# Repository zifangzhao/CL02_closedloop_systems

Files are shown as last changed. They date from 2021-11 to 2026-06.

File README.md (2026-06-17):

# CL02 Closed-Loop System

CL02 is a closed-loop electrophysiology trigger controller for detecting configured LFP oscillation features and driving timed stimulation outputs.

The project website is now built from the MkDocs source in [`docs/`](docs/) with configuration in [`mkdocs.yml`](mkdocs.yml). It documents:

- hardware connections and state indicators,
- Windows control-center setup and operation,
- trigger timing and external override behavior,
- firmware update workflow,
- firmware and MATLAB filter-design source locations.

## Local Documentation Preview

```powershell
pip install -r requirements.txt
mkdocs serve
```

For a strict build:

```powershell
mkdocs build --strict --verbose
```

## Repository Areas

| Area | Contents |
| --- | --- |
| `Windows` | CL02 control-center source, installers, and USB driver files. |
| `MCU` | STM32 firmware source, headers, filters, Keil project files, and firmware images. |
| `PCB` | CL02 board files, CAM outputs, assembly files, and BOM assets. |
| `Matlab` | Filter-design and validation scripts. |
| `docs` | MkDocs website source. |

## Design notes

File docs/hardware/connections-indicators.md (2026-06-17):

# Connections and Indicators

The original CL02 hardware note defines four external signal connections and three state indicators.

## Signal Connections

| Label | Role | Range or behavior |
| --- | --- | --- |
| IN0 | Analog input 0 | 0-3.3 V; can be configured with +1.5 V offset. |
| IN1 | Analog input 1 | 0-3.3 V; can be configured with +1.5 V offset. |
| DOUT | Digital trigger output | 0-3.3 V trigger output. |
| AOUT | Analog output | 0-3.3 V analog output. |

## State Indicators

| Indicator | Meaning |
| --- | --- |
| Ready | Closed-loop processor state. Slow blink means waiting; fast blink means estimating baseline; on means ready. |
| Detect | Trigger condition is armed. The final DOUT trigger still depends on stimulator settings. |
| Trigger | DOUT output state. |

!!! warning "Voltage compatibility"
    Check that every connected input accepts CL02 output voltage levels before enabling trigger output. DOUT is documented as 0-3.3 V.

## Bench Check

1. Connect only the bench input signal and a measurement instrument first.
2. Confirm IN0 or IN1 preview in the control center.
3. Confirm Ready state transitions.
4. Confirm DOUT timing and polarity on bench equipment before connecting a stimulator.

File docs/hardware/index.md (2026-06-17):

# Hardware

CL02 hardware exposes two analog inputs, one digital trigger output, one analog output, and visible state indicators for closed-loop state.

<div class="cl02-grid two">
  <a class="cl02-card cl02-card-link" href="connections-indicators/">
    <h3>Connections and indicators</h3>
    <p>IN0, IN1, DOUT, AOUT, and the Ready, Detect, and Trigger state indicators.</p>
  </a>
  <a class="cl02-card cl02-card-link" href="pcb/">
    <h3>PCB and assembly files</h3>
    <p>Public board files, fabrication outputs, and BOM-related files under the repository PCB directory.</p>
  </a>
</div>

<figure class="cl02-image-frame">
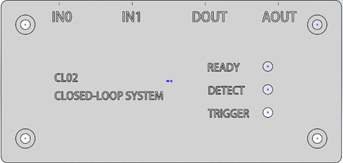
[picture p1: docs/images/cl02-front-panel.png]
CL02 front panel connection labels and state indicators
  
</figure>

## Hardware Asset Map

| Area | Repository path |
| --- | --- |
| V1 board files | [PCB/V1](https://github.com/zifangzhao/CL02_closedloop_systems/tree/V2.2/PCB/V1) |
| V2 board files | [PCB/V2](https://github.com/zifangzhao/CL02_closedloop_systems/tree/V2.2/PCB/V2) |
| V2 CAM outputs | [PCB/V2/CAMOutputs](https://github.com/zifangzhao/CL02_closedloop_systems/tree/V2.2/PCB/V2/CAMOutputs) |
| Firmware images | [MCU/MDK-ARM](https://github.com/zifangzhao/CL02_closedloop_systems/tree/V2.2/MCU/MDK-ARM) |
| Windows control software | [Windows](https://github.com/zifangzhao/CL02_closedloop_systems/tree/V2.2/Windows) |

## Compatibility Record

For each CL02 build or dataset, record:

| Record | Why it matters |
| --- | --- |
| PCB revision | Distinguishes board files and connector details. |
| Firmware filename | Ties trigger and DSP behavior to a specific image. |
| Control-center installer | Defines UI and serial command behavior. |
| Input source | Identifies signal range, offset, and coupling assumptions. |
| Output destination | Defines DOUT or AOUT interpretation by downstream hardware. |

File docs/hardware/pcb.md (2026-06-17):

# PCB and Assembly Files

The repository contains CL02 board assets for multiple revisions.

## Public Board Files

| Revision | Assets |
| --- | --- |
| V1 | `PCB/V1/CL02.sch`, `PCB/V1/CL02.brd`, and `CL02_default_BOM_values.xlsx`. |
| V2 | `PCB/V2/CL02_V2.sch`, `PCB/V2/CL02_V2.brd`, project files, CAM outputs, and assembly files. |

## Fabrication Outputs

The V2 folder includes CAM outputs:

- `PCB/V2/CAMOutputs/GerberFiles`
- `PCB/V2/CAMOutputs/DrillFiles`
- `PCB/V2/CAMOutputs/Assembly`
- `PCB/V2/CAMOutputs/CL02_V2_BOM.xlsx`
- `PCB/V2/CAMOutputs/CL02_V2.zip`

## Documentation Practice

When documenting or reproducing a CL02 build, include the board revision, CAM output archive, BOM file, firmware image, and Windows control-center version. Do not infer connector behavior from board-file names alone; verify against the hardware labels and bench measurements.

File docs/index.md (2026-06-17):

---
hide:
  - navigation
  - toc
---

<section class="cl02-hero">
  <div>
    <h1>A compact closed-loop controller for LFP-triggered stimulation</h1>
    <p>CL02 detects configured local-field-potential oscillation features from analog inputs and drives timed trigger outputs for closed-loop electrophysiology experiments.</p>
    <div class="cl02-actions">
      <a class="md-button md-button--primary" href="getting-started/">Get Started</a>
      <a class="md-button" href="hardware/">Hardware</a>
      <a class="md-button" href="software/">Software</a>
      <a class="md-button" href="firmware-analysis/">Firmware</a>
      <a class="md-button" href="https://github.com/zifangzhao/CL02_closedloop_systems">GitHub</a>
    </div>
    <div class="cl02-signal-row">
      <span>IN0 and IN1 analog inputs</span>
      <span>DOUT trigger output</span>
      <span>AOUT analog output</span>
      <span>1 kHz DSP workflow</span>
      <span>Windows control center</span>
    </div>
  </div>
  <div class="cl02-hero-media cl02-hero-media-tiled">
    <figure class="cl02-hero-tile cl02-device-tile">
      CL02 front panel with IN0, IN1, DOUT, AOUT, and status indicators
      <figcaption class="cl02-caption">The CL02 front panel exposes two analog inputs, digital and analog outputs, and three state indicators for closed-loop readiness and trigger state.</figcaption>
    </figure>
    <figure class="cl02-hero-tile cl02-ui-tile">
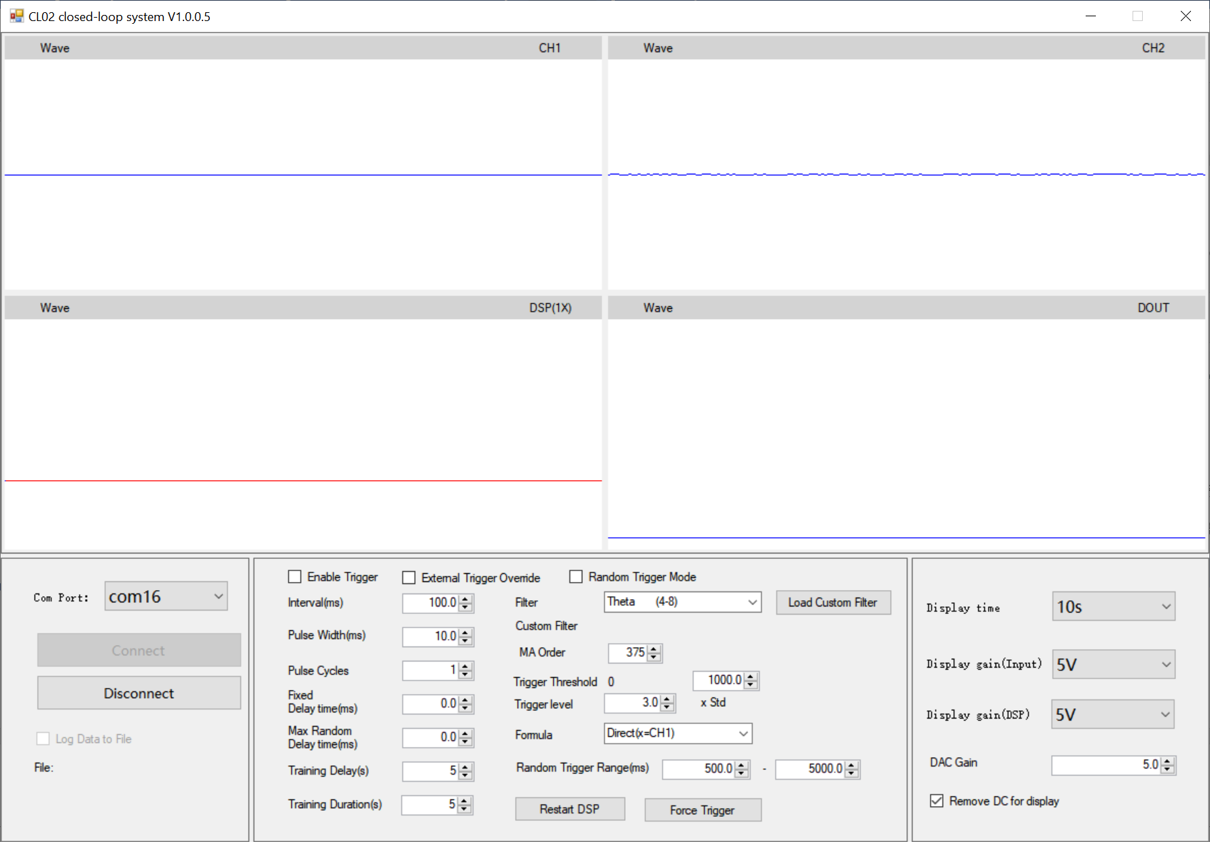
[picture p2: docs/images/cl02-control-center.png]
CL02 Windows control center showing waveforms and trigger settings
      
    </figure>
  </div>
</section>

<section class="cl02-section">
  <div class="cl02-grid two">
    <div class="cl02-card">
      <h2>Current Public Workflow</h2>
      <p><strong>Stable public scope:</strong> connect the CL02 device over USB, configure filters and trigger timing in the Windows control center, and use DOUT or AOUT to drive downstream stimulation hardware.</p>
    </div>
    <div class="cl02-card">
      <h2>Release Record</h2>
      <p>Record the installer file, firmware image, PCB revision, filter file, stimulus timing parameters, and threshold settings with each experiment so trigger behavior remains reproducible.</p>
    </div>
  </div>

  <div class="cl02-grid">
    <div class="cl02-card">
      <h3>Run a first bench test</h3>
      <p><a href="getting-started/installation/">Install</a> -> <a href="getting-started/first-run/">connect</a> -> configure a conservative trigger -> verify DOUT timing.</p>
    </div>
    <div class="cl02-card">
      <h3>Prepare hardware</h3>
      <p><a href="hardware/connections-indicators/">Connection map</a> -> status indicators -> stimulator input checks -> PCB revision notes.</p>
    </div>
    <div class="cl02-card">
      <h3>Tune detection</h3>
      <p><a href="software/filters/">Filter choice</a> -> moving-average order -> baseline training window -> threshold or trigger-level setting.</p>
    </div>
    <div class="cl02-card">
      <h3>Update firmware</h3>
      <p><a href="getting-started/firmware-update/">DFU mode</a> -> choose a repository firmware image -> upgrade -> return the switch to Run mode.</p>
    </div>
  </div>
</section>

<section class="cl02-section">
  <h2>Closed-Loop Signal Path</h2>
  <p>CL02 routes analog input through configured filtering and trigger control before asserting the stimulation output.</p>
  <div class="cl02-flow" aria-label="CL02 signal path">
    <div>Analog input</div>
    <div>DSP filter</div>
    <div>Envelope or metric</div>
    <div>Baseline training</div>
    <div>Threshold test</div>
    <div>DOUT or AOUT</div>
  </div>
</section>

<section class="cl02-section">
  <h2>Interface and I/O Summary</h2>
  <div class="cl02-spec-scroll" role="region" aria-label="CL02 input output summary" tabindex="0">
    <table class="cl02-spec-table">
      <thead>
        <tr>
          <th>Signal or control</th>
          <th>Public behavior</th>
          <th>Documentation entry</th>
        </tr>
      </thead>
      <tbody>
        <tr><td>IN0</td><td>Analog input 0, 0-3.3 V, configurable with +1.5 V offset.</td><td><a href="hardware/connections-indicators/">Connections</a></td></tr>
        <tr><td>IN1</td><td>Analog input 1, 0-3.3 V, configurable with +1.5 V offset.</td><td><a href="hardware/connections-indicators/">Connections</a></td></tr>
        <tr><td>DOUT</td><td>Digital trigger output, 0-3.3 V.</td><td><a href="software/trigger-logic/">Trigger Logic</a></td></tr>
        <tr><td>AOUT</td><td>Analog output, 0-3.3 V.</td><td><a href="hardware/connections-indicators/">Connections</a></td></tr>
        <tr><td>Ready</td><td>Closed-loop processor state: slow blink while waiting, fast blink while estimating baseline, on when ready.</td><td><a href="hardware/connections-indicators/">Indicators</a></td></tr>
        <tr><td>Detect</td><td>Indicates that a trigger condition is armed; DOUT behavior still depends on stimulator settings.</td><td><a href="hardware/connections-indicators/">Indicators</a></td></tr>
        <tr><td>Trigger</td><td>Indicates DOUT state.</td><td><a href="hardware/connections-indicators/">Indicators</a></td></tr>
      </tbody>
    </table>
  </div>
</section>

<section class="cl02-section">
  <h2>Operator Controls</h2>
  <p>The Windows control center presents waveform preview, serial connection, trigger timing, DSP filter selection, and display scaling in one bench-facing interface.</p>
  <div class="cl02-grid">
    <div class="cl02-card">
      <h3>Connection</h3>
      <p>Choose the COM port, connect to the device, and optionally log data to a file during preview.</p>
    </div>
    <div class="cl02-card">
      <h3>Trigger timing</h3>
      <p>Set interval, pulse width, pulse cycles, fixed delay, random delay, and training delay or duration.</p>
    </div>
    <div class="cl02-card">
      <h3>DSP configuration</h3>
      <p>Select filter, formula, moving-average order, trigger threshold, trigger level, and optional custom filters.</p>
    </div>
    <div class="cl02-card">
      <h3>Manual checks</h3>
      <p>Restart DSP or force a trigger during bench validation before moving to experiment hardware.</p>
    </div>
    <div class="cl02-card">
      <h3>External override</h3>
      <p>Read an int32 control value from <code>d:\cl02_control.bin</code> to mask DOUT in the experimental override workflow.</p>
    </div>
    <div class="cl02-card">
      <h3>Display scaling</h3>
      <p>Select display time, input gain, DSP gain, DAC gain, and optional DC removal for waveform review.</p>
    </div>
  </div>
</section>

<section class="cl02-section">
  <h2>System Overview</h2>
  <p>A typical session starts with a bench connection, then moves through filter selection, baseline training, trigger verification, and experiment logging.</p>
  <figure class="cl02-image-frame">
    CL02 Windows control center with waveform and closed-loop settings
  </figure>
</section>

<section class="cl02-section">
  <h2>Quick Start</h2>
  <div class="cl02-grid two">
    <div class="cl02-card">
      <h3>Install software</h3>
      <p>Use the installer under <code>Windows</code> and install the CL02 USB driver manually if Windows does not bind a usable COM port.</p>
    </div>
    <div class="cl02-card">
      <h3>Connect hardware</h3>
      <p>Wire IN0 or IN1, connect DOUT or AOUT to the downstream device, and confirm voltage compatibility before enabling triggers.</p>
    </div>
    <div class="cl02-card">
      <h3>Train and trigger</h3>
      <p>Select filter, moving-average order, training window, threshold, interval, pulse width, and delay before enabling output.</p>
    </div>
    <div class="cl02-card">
      <h3>Save a record</h3>
      <p>Log the installer version, firmware file, trigger settings, filter file, and hardware connections used for the run.</p>
    </div>
  </div>
</section>

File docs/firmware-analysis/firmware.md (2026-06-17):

# Firmware

CL02 firmware source is organized under `MCU`.

## High-Signal Source Files

| File | Role |
| --- | --- |
| `MCU/Src/CE32_ClosedLoop.c` | Closed-loop modes, baseline training, threshold checks, random-trigger update, and trigger actions. |
| `MCU/Src/CE32_StimControl.c` | Stimulation-control behavior and output timing support. |
| `MCU/Src/CE32_COMMAND.c` | Command handling for host-device communication. |
| `MCU/Src/CL02_Server.c` | CL02 server-side firmware behavior. |
| `MCU/Inc/CE32_filterDef.h` | Filter coefficient include map. |
| `MCU/Inc/CE32_ClosedLoop.h` | Closed-loop type and interface definitions. |

## Firmware Images

Prebuilt images and historical images are under `MCU/MDK-ARM`. Record the exact image filename used in each run.

## Firmware Behavior Notes

The firmware source includes closed-loop modes such as disabled, single, double, cascade, gated, random, and Hilbert-transform variants. Public experiment notes should state the mode and filter path used rather than relying only on a UI screenshot.

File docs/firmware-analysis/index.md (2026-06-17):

# Firmware and Analysis

The CL02 repository includes STM32 firmware source, firmware image artifacts, and MATLAB tools for filter design and validation.

<div class="cl02-grid two">
  <a class="cl02-card cl02-card-link" href="firmware/">
    <h3>Firmware</h3>
    <p>STM32 source files, command handling, closed-loop logic, stimulation control, and prebuilt images.</p>
  </a>
  <a class="cl02-card cl02-card-link" href="matlab/">
    <h3>MATLAB tools</h3>
    <p>Filter design, coefficient generation, validation scripts, and file-control example workflows.</p>
  </a>
</div>

## Core Repository Areas

| Area | Purpose |
| --- | --- |
| `MCU/Src` | Firmware source files, including command, closed-loop, stimulation, data, USB, and UART modules. |
| `MCU/Inc` | Firmware headers and generated filter coefficient headers. |
| `MCU/MDK-ARM` | Keil project files and firmware image artifacts. |
| `Matlab` | Filter-design and validation scripts. |
| `Windows` | Control-center application and installer assets. |

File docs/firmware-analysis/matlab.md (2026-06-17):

# MATLAB Tools

The `Matlab` folder contains scripts for filter generation, validation, and helper workflows.

## Key Files

| File | Role |
| --- | --- |
| `CL02_filterDesigner.m` | CL02 filter design entry point. |
| `CL02_genFilter_withData.m` | Filter generation using data-driven workflow. |
| `script_validate_CL02_filterDesigner.m` | Minimal validation entry for CL02 filter design. |
| `CE32_filterDesigner.m` | Shared CE32 filter design helper. |
| `CE32_filterGen_SOS.m` | Second-order-section coefficient generation. |
| `CE32_filterDef.h` | Generated or source filter definition map used by firmware-side includes. |
| `readmulti_frank.m` | MATLAB data helper included in the repository. |

## Validation Example

The repository validation script constructs a filter and opens MATLAB visualization:

```matlab
Hd=CE32_filterDesigner(100,1000,2);
fvtool(Hd,'fs',1000);
```

## Documentation Practice

When custom filters are used, preserve:

1. The MATLAB script version.
2. The input parameters.
3. The generated coefficient file.
4. The firmware image that consumed the coefficients.
5. The control-center screenshot or parameter export for the run.

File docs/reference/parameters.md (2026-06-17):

# Parameters

This table mirrors the public control-center parameters described in the original README and visible UI.

| Parameter | Meaning |
| --- | --- |
| Connect | Start communication with the connected CL02 device. |
| Disconnect | Disconnect the device; the original note states the device remains in its state. |
| Enable Trigger | Enable DOUT signaling. |
| External Trigger Override | Experimental file-based int32 override used to mask DOUT. |
| Interval | Minimum trigger interval, in milliseconds. |
| Pulse width | Width of each individual trigger pulse, in milliseconds. |
| Pulse cycles | Number of pulse cycles in a trigger event. |
| Fixed delay | Fixed delay between trigger detection and DOUT output. |
| Max random delay | Random delay range added between trigger detection and DOUT output. |
| Train start | Delay before closed-loop processor initiation after setting. |
| Train duration | Baseline calculation window duration. |
| MA order | Moving-average window order in samples; the original note references `fs=1000`. |
| Filter | DSP filter selection. |
| Custom filter | Operator-loaded filter file. |
| Trigger threshold | Absolute threshold setting. |
| Trigger level | Trigger threshold based on a multiple of baseline level. |
| Formula | Input signal selected for DSP computation. |
| Random trigger range | Time range between triggers in random-trigger mode. |
| Display time | Waveform preview time window. |
| Display gain | Waveform scaling for input and DSP preview. |
| DAC gain | Analog-output gain setting. |
| Remove DC for display | Display-side DC removal for waveform preview. |

## Experiment Record Minimum

At minimum, save the firmware image, installer version, PCB revision, input channel, output channel, filter, trigger threshold or trigger level, train start, train duration, interval, pulse width, delay settings, and whether external override was enabled.

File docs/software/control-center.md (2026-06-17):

# Control Center

The CL02 control center is the main operator interface for connecting the device, viewing waveforms, and configuring closed-loop behavior.

<figure class="cl02-image-frame">
  CL02 Windows control center
</figure>

## Main Areas

| Area | Purpose |
| --- | --- |
| Waveform panels | Preview CH1, CH2, DSP output, and DOUT state. |
| COM port and connect buttons | Select the serial port, connect, disconnect, and optionally log data to file. |
| Trigger timing controls | Set interval, pulse width, pulse cycles, fixed delay, random delay, training delay, and training duration. |
| DSP controls | Select filter, custom filter, moving-average order, threshold, trigger level, and formula. |
| Manual actions | Restart DSP or force trigger for controlled bench validation. |
| Display controls | Select display time, input gain, DSP gain, DAC gain, and DC removal. |

## Connection Flow

1. Select the COM port.
2. Connect.
3. Review waveform preview.
4. Configure output timing and DSP settings.
5. Enable trigger only after bench validation.
6. Disconnect before rewiring hardware.

!!! tip "Record parameter values"
    A screenshot is useful, but the experiment note should include the actual trigger interval, pulse width, delay, filter, moving-average order, threshold, and firmware image.

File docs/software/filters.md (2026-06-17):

# Filters

CL02 includes built-in filter coefficient headers and MATLAB tools for generating filter definitions.

## Built-In Filter Families

The firmware include tree contains filter headers for commonly used bands, including delta, theta, alpha, beta, gamma, high-gamma, epilepsy-band, sharp-wave, ripple, and ripple-1 style entries. The public headers include band-pass filters, low-pass filters, and Hilbert-transform filter variants at the CL02 DSP sample-rate workflow.

Examples from `MCU/Inc/CE32_filterDef.h` include:

| Family | Representative headers |
| --- | --- |
| Delta | `fdacoefs_BPF_D_1.5_5.5Hz@1000_ord1_SOS.h` |
| Theta | `fdacoefs_BPF_T_4_12Hz@1000_ord1_SOS.h` |
| Alpha | `fdacoefs_BPF_A_8_13Hz@1000_ord1_SOS.h` |
| Beta | `fdacoefs_BPF_B_13_30Hz@1000_ord1_SOS.h` |
| Gamma | `fdacoefs_BPF_G_30_80Hz@1000_ord1_SOS.h` |
| Ripple | `fdacoefs_BPF_R_110_250Hz@1000_ord1_SOS.h` |
| Ripple 1 | `fdacoefs_BPF_R1_100_200Hz@1000_ord1_SOS.h` |

## Custom Filters

The control center exposes custom filter loading. Keep custom filter files alongside the experiment record and document which DSP channel used each file.

## MATLAB Filter Tools

The `Matlab` folder contains CL02 and CE32 filter-design scripts, including `CL02_filterDesigner.m`, `CE32_filterDesigner.m`, and validation scripts. Use these scripts as the auditable source for generated coefficients rather than hand-editing coefficient headers.

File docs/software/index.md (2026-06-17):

# Software

CL02 software centers on the Windows control application for waveform preview, DSP and trigger configuration, serial communication, and output testing.

<div class="cl02-grid two">
  <a class="cl02-card cl02-card-link" href="control-center/">
    <h3>Control Center</h3>
    <p>Waveform panels, COM-port connection, trigger timing, filter selection, custom filter loading, and display scaling.</p>
  </a>
  <a class="cl02-card cl02-card-link" href="trigger-logic/">
    <h3>Trigger Logic</h3>
    <p>Training window, baseline estimation, threshold or level logic, pulse width, interval, delay, and random-delay behavior.</p>
  </a>
  <a class="cl02-card cl02-card-link" href="external-control/">
    <h3>External Control</h3>
    <p>Experimental int32 file override through <code>d:\cl02_control.bin</code>.</p>
  </a>
  <a class="cl02-card cl02-card-link" href="filters/">
    <h3>Filters</h3>
    <p>Built-in oscillation bands, moving-average order, custom filter files, and MATLAB filter-generation tools.</p>
  </a>
</div>

<figure class="cl02-image-frame">
  CL02 control center overview
</figure>

## Control Surface

The control center combines four display panels with trigger and DSP configuration. Public documentation should treat screenshots as operator guidance, not a replacement for recording the exact parameter values used in a run.

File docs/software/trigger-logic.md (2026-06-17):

# Trigger Logic

CL02 trigger behavior combines DSP output, baseline training, threshold logic, timing constraints, and output gating.

<figure class="cl02-image-frame">
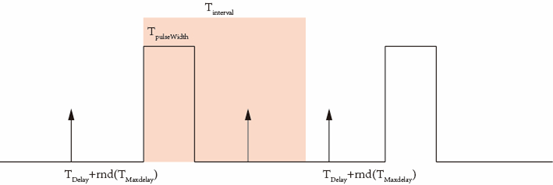
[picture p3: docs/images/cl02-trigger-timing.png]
CL02 trigger timing diagram showing delay, random delay, pulse width, and interval
  
</figure>

## Timing Controls

| Parameter | Meaning |
| --- | --- |
| Interval | Minimum interval between triggers, in milliseconds. |
| Pulse width | Width of each individual trigger pulse, in milliseconds. |
| Pulse cycles | Number of pulse cycles in the configured output event. |
| Fixed delay | Fixed delay added between trigger detection and DOUT assertion. |
| Max random delay | Maximum random delay added between detection and DOUT assertion. |
| Train start | Delay before closed-loop processor training begins. |
| Train duration | Baseline calculation window duration. |

## Detection Controls

| Parameter | Meaning |
| --- | --- |
| MA order | Moving-average window order. The original README notes sample units with `fs=1000`. |
| Filter | Built-in or custom filter used by the DSP path. |
| Trigger threshold | Absolute trigger threshold setting. |
| Trigger level | Threshold based on a multiple of the baseline level. |
| Formula | Input signal selected for DSP computation. |
| Random trigger range | Time range between triggers in random-trigger mode. |

## Recommended Validation

1. Disable trigger output while confirming signal preview.
2. Confirm the baseline state reaches Ready.
3. Enable output with conservative interval and pulse width.
4. Measure DOUT timing externally.
5. Document configured timing and measured timing.

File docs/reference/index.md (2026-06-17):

# Reference

The reference section collects operator parameters, troubleshooting notes, and contribution guidance.

<div class="cl02-grid two">
  <a class="cl02-card cl02-card-link" href="parameters/">
    <h3>Parameters</h3>
    <p>Control-center parameter names and the public behavior documented in the original instructions.</p>
  </a>
  <a class="cl02-card cl02-card-link" href="troubleshooting/">
    <h3>Troubleshooting</h3>
    <p>Connection, driver, DFU, trigger, and external-control checks.</p>
  </a>
  <a class="cl02-card cl02-card-link" href="contributing/">
    <h3>Contributing</h3>
    <p>How to keep CL02 documentation source-faithful and reproducible.</p>
  </a>
</div>

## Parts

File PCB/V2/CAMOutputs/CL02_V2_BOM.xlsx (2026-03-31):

Qty | Value | Device | Package | Parts | Description | BOM | MF | MPN | OC_FARNELL | OC_NEWARK | POPULARITY | SPICEMODEL | SPICEPREFIX
5 |  | LED0603 | CHIPLED_0603 | DET, ENABLE, PWR, READY, STIM | https://www.digikey.com/en/products/detail/liteon/LTST-C194TBKT/2356225
1 | 0Ohm | SOLDERJUMPER | SOLDERJUMPER_ARROW_NOPASTE | SJ1 | https://www.digikey.com/en/products/detail/yageo/RC0402JR-070RL/726406
1 |  | SWITCH_DPDT | DPDT_SMT_JS202011SCQN | SW1 | https://www.digikey.com/en/products/detail/c-k/JS202011SCQN/2094299?s=N4IgTCBcDaIFIGUwAYUEY0IMIEUByIAugL5A
3 | 1.5k | RR0402 | R0402 | R5, R6, R7 | https://www.digikey.com/en/products/detail/panasonic-electronic-components/ERA-2AEB152X/1706009 |  |  |  |  |  |  | NONE | R
3 | 100k | RR0402 | R0402 | R9, R11, R13 | https://www.digikey.com/en/products/detail/yageo/RC0402FR-07100KL/726526 |  |  |  |  |  |  | NONE | R
13 | 10k | RR0402 | R0402 | R1, R2, R3, R4, R8, R10, R12, R14, R15, R16, R23, R24, R25 | https://www.digikey.com/en/products/detail/yageo/RC0402JR-0710KL/726418 |  |  |  |  |  |  | NONE | R
15 | 10u | CC0402 | C0402 | C3, C4, C5, C6, C7, C8, C9, C10, C11, C14, C15, C16, C18, C19, C22 | https://www.digikey.com/en/products/detail/samsung-electro-mechanics/CL05A106MP5NUNC/3887108 |  |  |  |  |  |  | NONE | C
2 | 18p | CC0402 | C0402 | C1, C2 | https://www.digikey.com/en/products/detail/kemet/CBR04C180F5GAC/3479640 |  |  |  |  |  |  | NONE | C
1 | 2.54MM_2X5 | 2.54MM_2X5 | 2.54MM_2X5 | U$9 | https://www.digikey.com/en/products/detail/sullins-connector-solutions/SFH11-PBPC-D05-ST-BK/1990087
1 | 20k | RR0402 | R0402 | R17 | https://www.digikey.com/en/products/detail/yageo/RC0402FR-0720KL/726557 |  |  |  |  |  |  | NONE | R
4 | 33n | CC0402 | C0402 | C12, C13, C17, C21 | https://www.digikey.com/en/products/detail/taiyo-yuden/TMK105BJ333KV-F/4157227 |  |  |  |  |  |  | NONE | C
4 | AD8532 | AD8542R | SO8 | IC1, IC2, IC3, IC4 | https://www.digikey.com/en/products/detail/analog-devices-inc/AD8542ARZ-REEL7/652863 |  | ALTERA CORPORATION | AD8542ARZ-REEL | 1424150 | 59K6827 | 0
6 | BNC_8MM | BNC_8MM | BNC_V_8MM | A_OUT1, A_OUT2, D_OUT, IN1, IN2, IN3 | https://www.amazon.com/Superbat-Connector-Bulkhead-Monitoring-Transceiver/dp/B09V56M8F4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
1 | DNP | C-GRID-03-70543 | 70543-03 | X1 |  |  | MOLEX |  | unknown | unknown | 3
1 | CUS-12B | CUS-12B | CUS-12B | U$12 | https://www.digikey.com/en/products/detail/hirose-electric-co-ltd/ZX62R-B-5P-30/5994740
1 | DNP | EEPROM_I2C_SOIC8_GENERIC | SOIC8_150MIL | U2
1 | DNP | JST_8PIN | JSTPH8 | CN5
1 | ECS-120-18-4X-CKM | XTAL/S | QS | Q1 | https://www.digikey.com/en/products/detail/ecs-inc/ECS-120-18-4X-CKM/12349416
12 | MMSZ4684T1GOSCT-ND | DIODE_ZENER_SOD-123 | SOD-123 | D2, D3, D4, D6, D7, D8, D9, D10, D11, D12, D13, D14 | https://www.digikey.com/en/products/detail/onsemi/MMSZ4684T1G/919718
1 | STM32F373CCT6 | STM32F373CCT6 | LQFP48 | U$1 | https://www.digikey.com/en/products/detail/stmicroelectronics/STM32F373CCT6/3648271
1 | TERMINAL_BLOCK_8-3.5MM | TERMINAL_BLOCK_8-3.5MM | TERMINAL_BLOCK_3.5MM_8 | S1 | https://www.digikey.com/en/products/detail/on-shore-technology-inc/OSTTE080161/614590
2 | DNP | TESTPOINT | TESTPOINT | VCC, VMID
1 | TPS79333 | TPS79333 | TSOT-23-5 | U1 | https://www.digikey.com/en/products/detail/texas-instruments/TPS79333DBVR/476150
1 | ZX62R-B-5P(30) | MICRO-USB-ZX62R-B-5P | ZX62R-B-5P | U$10 | https://www.digikey.com/en/products/detail/hirose-electric-co-ltd/ZX62R-B-5P-30/5994740
 | *DNP=Do not place

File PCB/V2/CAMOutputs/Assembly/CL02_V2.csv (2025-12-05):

Qty | Value | Device | Package | Parts | Description | BOM | MF | MPN | OC_FARNELL | OC_NEWARK | POPULARITY | SPICEMODEL | SPICEPREFIX
5 |  | LED0603 | CHIPLED_0603 | DET, ENABLE, PWR, READY, STIM | LED
1 |  | SOLDERJUMPER | SOLDERJUMPER_ARROW_NOPASTE | SJ1 | SMD Solder JUMPER | EXCLUDE
1 |  | SWITCH_DPDT | DPDT_SMT_JS202011SCQN | SW1 | Switch - DPDT
3 | 1.5k | RR0402 | R0402 | R5, R6, R7 | RESISTOR, European symbol |  |  |  |  |  |  | NONE | R
3 | 100k | RR0402 | R0402 | R9, R11, R13 | RESISTOR, European symbol |  |  |  |  |  |  | NONE | R
13 | 10k | RR0402 | R0402 | R1, R2, R3, R4, R8, R10, R12, R14, R15, R16, R23, R24, R25 | RESISTOR, European symbol |  |  |  |  |  |  | NONE | R
15 | 10u | CC0402 | C0402 | C3, C4, C5, C6, C7, C8, C9, C10, C11, C14, C15, C16, C18, C19, C22 | CAPACITOR, European symbol |  |  |  |  |  |  | NONE | C
2 | 18p | CC0402 | C0402 | C1, C2 | CAPACITOR, European symbol |  |  |  |  |  |  | NONE | C
1 | 2.54MM_2X5 | 2.54MM_2X5 | 2.54MM_2X5 | U$9
1 | 20k | RR0402 | R0402 | R17 | RESISTOR, European symbol |  |  |  |  |  |  | NONE | R
4 | 33n | CC0402 | C0402 | C12, C13, C17, C21 | CAPACITOR, European symbol |  |  |  |  |  |  | NONE | C
4 | AD8532 | AD8542R | SO8 | IC1, IC2, IC3, IC4 | General-Purpose CMOS Rail-to-Rail Amplifiers |  | ALTERA CORPORATION | AD8542ARZ-REEL | 1424150 | 59K6827 | 0
6 | BNC_8MM | BNC_8MM | BNC_V_8MM | A_OUT1, A_OUT2, D_OUT, IN1, IN2, IN3
1 | C-GRID-03-70543 | C-GRID-03-70543 | 70543-03 | X1 | CONNECTOR |  | MOLEX |  | unknown | unknown | 3
1 | CUS-12B | CUS-12B | CUS-12B | U$12 | Toggle Switch
1 | DNP | EEPROM_I2C_SOIC8_GENERIC | SOIC8_150MIL | U2 | Note: The same pinout is used for many I2C EEPROMs in SOIC8(150mil) from a variety of manufacturers and in various sizes.
1 | DNP | JST_8PIN | JSTPH8 | CN5 | JST 8-Pin Right-Angle Connector
1 | ECS-120-18-4X-CKM | XTAL/S | QS | Q1 | CRYSTAL
12 | MMSZ4684T1GOSCT-ND | DIODE_ZENER_SOD-123 | SOD-123 | D2, D3, D4, D6, D7, D8, D9, D10, D11, D12, D13, D14 | Zener diode
1 | STM32F373CCT6 | STM32F373CCT6 | LQFP48 | U$1
1 | TERMINAL_BLOCK_8-3.5MM | TERMINAL_BLOCK_8-3.5MM | TERMINAL_BLOCK_3.5MM_8 | S1 | 8-point terminal block
2 | TESTPOINT | TESTPOINT | TESTPOINT | VCC, VMID
1 | TPS79333 | TPS79333 | TSOT-23-5 | U1
1 | ZX62R-B-5P(30) | MICRO-USB-ZX62R-B-5P | ZX62R-B-5P | U$10 | Hirose Micro USB Connector

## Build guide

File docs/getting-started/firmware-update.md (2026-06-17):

# Firmware Update

CL02 firmware images are distributed under `MCU/MDK-ARM`. The original workflow uses ST DfuSe Demo.

<figure class="cl02-image-frame">
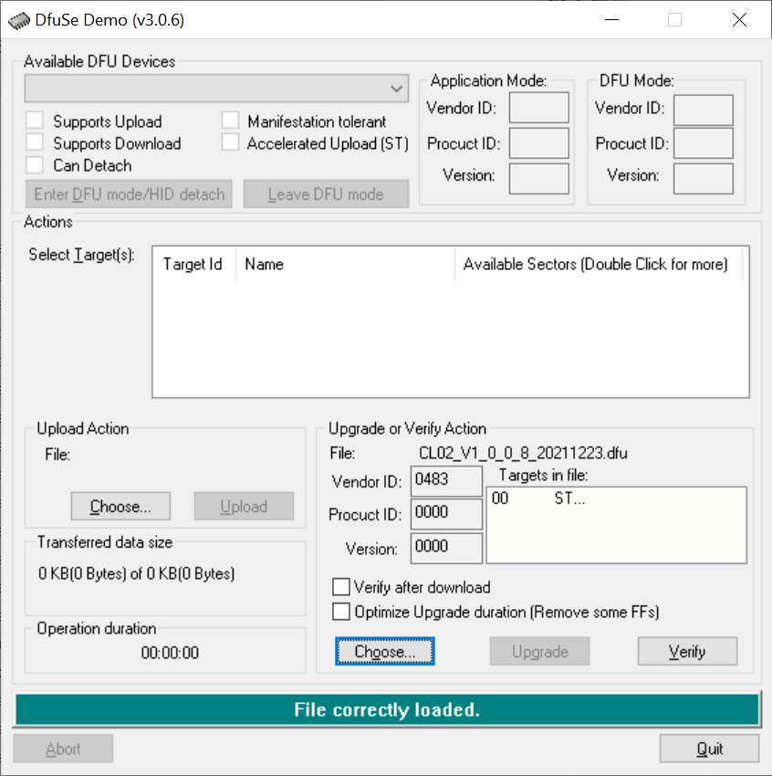
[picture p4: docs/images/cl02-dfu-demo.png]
DfuSe Demo firmware update screen with a CL02 DFU image loaded
  
</figure>

## Update Procedure

1. Install ST DfuSe Demo from STMicroelectronics.
2. Power the CL02 device off.
3. Move the hardware switch under the USB connector to DFU mode. In the original hardware note, the side opposite the BNC connector is DFU mode.
4. Connect the CL02 device over USB.
5. Open DfuSe Demo.
6. Choose the intended `.dfu` firmware image from `MCU/MDK-ARM`.
7. Click upgrade.
8. Disconnect USB after the update completes.
9. Power the device off.
10. Move the switch back to Run mode. In the original hardware note, the side matching the BNC connector is Run mode.
11. Reconnect and validate with a bench test.

## Firmware Image Record

Record the exact firmware filename used. The repository contains multiple historical firmware images, and behavior may differ across versions.

| Record | Example source |
| --- | --- |
| Firmware image | `MCU/MDK-ARM/*.dfu` or checked `.hex` image |
| Control center installer | `Windows/*.exe` |
| PCB revision | `PCB/V1` or `PCB/V2` |
| Trigger settings | Saved experiment note or screenshot |

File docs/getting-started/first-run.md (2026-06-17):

# First Run

Use a conservative bench run to confirm that the control center, serial connection, DSP settings, and output timing all behave as expected.

## Connect

1. Launch the CL02 control center.
2. Select the COM port for the connected CL02 device.
3. Click <span class="cl02-button-label primary">Connect</span>.
4. Confirm that waveform panels update.

## Configure a Safe Trigger Profile

Start with settings that are easy to verify on a scope or downstream acquisition system:

| Setting | First-run guidance |
| --- | --- |
| Enable Trigger | Leave disabled until the input and timing settings are reviewed. |
| Interval | Use a long interval for early bench testing. |
| Pulse width | Use a pulse width accepted by the downstream device. |
| Fixed delay | Start at `0 ms` unless the experiment requires deterministic delay. |
| Max random delay | Start at `0 ms` unless validating random-delay behavior. |
| Training delay | Leave enough time to observe waiting and baseline states. |
| Training duration | Use a short but stable baseline window for the bench signal. |
| Filter | Choose the frequency band that matches the bench signal. |
| Trigger threshold or level | Start high enough to avoid accidental triggering. |

## Verify Output

1. Confirm Ready state transitions from waiting to baseline estimation to ready.
2. Enable trigger output only after the input signal is visible and the threshold is reviewed.
3. Observe DOUT or AOUT with bench equipment.
4. Use <span class="cl02-button-label">Force Trigger</span> only when the output path is safe to test.
5. Document any mismatch between configured timing and measured output timing.

!!! warning "Downstream stimulation safety"
    CL02 can assert trigger outputs. Confirm downstream stimulator enable state, pulse interpretation, voltage compatibility, and isolation before connecting stimulation hardware.

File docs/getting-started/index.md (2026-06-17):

# Getting Started

CL02 setup moves from software installation to a conservative bench test before use with experiment hardware.

<div class="cl02-grid two">
  <a class="cl02-card cl02-card-link" href="installation/">
    <h3>1. Install</h3>
    <p>Install the Windows control center, connect the USB device, and install the driver manually if Windows does not expose a usable COM port.</p>
  </a>
  <a class="cl02-card cl02-card-link" href="first-run/">
    <h3>2. First run</h3>
    <p>Select the COM port, connect, configure a known-safe trigger timing profile, and verify the waveform and output path.</p>
  </a>
  <a class="cl02-card cl02-card-link" href="firmware-update/">
    <h3>3. Firmware update</h3>
    <p>Use ST DfuSe Demo with the hardware DFU switch and a checked firmware image from the repository.</p>
  </a>
</div>

## Before You Begin

- Windows with permission to install desktop software and USB drivers.
- A CL02 device connected over USB.
- A downstream stimulator or measurement device that accepts 0-3.3 V logic for DOUT if DOUT is used.
- A bench measurement path for first validation, such as an oscilloscope or compatible data acquisition input.
- A documented firmware image and installer version for the device under test.

!!! warning "Bench-test first"
    Do not enable stimulation output in an animal experiment until DOUT or AOUT timing, voltage, polarity, and downstream-device behavior have been verified on the bench.

## Repository Asset Map

| Asset | Repository path |
| --- | --- |
| Windows installers | [Windows](https://github.com/zifangzhao/CL02_closedloop_systems/tree/V2.2/Windows) |
| USB driver | [Windows/CL02_driver.inf](https://github.com/zifangzhao/CL02_closedloop_systems/blob/V2.2/Windows/CL02_driver.inf) |
| Firmware images | [MCU/MDK-ARM](https://github.com/zifangzhao/CL02_closedloop_systems/tree/V2.2/MCU/MDK-ARM) |
| Firmware source | [MCU/Src](https://github.com/zifangzhao/CL02_closedloop_systems/tree/V2.2/MCU/Src) and [MCU/Inc](https://github.com/zifangzhao/CL02_closedloop_systems/tree/V2.2/MCU/Inc) |
| PCB files | [PCB](https://github.com/zifangzhao/CL02_closedloop_systems/tree/V2.2/PCB) |
| MATLAB tools | [Matlab](https://github.com/zifangzhao/CL02_closedloop_systems/tree/V2.2/Matlab) |

## First Success Target

1. The CL02 device appears as a COM port.
2. The control center opens and connects.
3. Waveform preview updates for the configured input channel.
4. A conservative trigger profile produces the expected DOUT or AOUT behavior on bench equipment.
5. The operator records the installer file, firmware image, filter selection, threshold, trigger timing, and hardware cabling used.

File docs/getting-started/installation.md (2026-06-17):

# Installation

The CL02 control workflow uses the Windows application distributed in the repository.

## Install the Windows Control Center

1. Open the repository `Windows` folder.
2. Choose the installer that matches the device and release you intend to use.
3. Run the installer.
4. If the installer or application is blocked by local security software, whitelist the known CL02 installer path or retry in a controlled setup environment.
5. Start the CL02 control center after installation.

## Connect the Device

1. Connect CL02 over USB.
2. Open Windows Device Manager and confirm that a COM port is present.
3. If Windows does not bind a useful COM port automatically, install `Windows/CL02_driver.inf` manually.
4. Restart the control center after driver installation.

!!! tip "Keep the exact installer name"
    The repository contains multiple installer versions. Record the file name used for each experiment or bench validation so the control-center behavior can be reproduced later.

## Driver Notes

The original CL02 instructions point to manual Windows driver installation when the device cannot connect. On modern Windows systems, this usually means selecting the CL02 `.inf` file from Device Manager and confirming the driver binding for the USB serial device.

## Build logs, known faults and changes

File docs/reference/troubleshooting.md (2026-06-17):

# Troubleshooting

## Device Does Not Connect

1. Confirm USB cable and power state.
2. Confirm the device appears as a COM port in Windows Device Manager.
3. Install `Windows/CL02_driver.inf` manually if Windows does not bind the driver.
4. Restart the control center and reselect the COM port.
5. Check that no other program is holding the same COM port.

## Firmware Update Does Not Start

1. Power the device off before switching modes.
2. Confirm the hardware switch is in DFU mode.
3. Reconnect USB after entering DFU mode.
4. Confirm DfuSe Demo sees the DFU device.
5. Choose a `.dfu` image from `MCU/MDK-ARM`.

## Trigger Does Not Appear on DOUT

1. Confirm DOUT is connected to bench measurement equipment.
2. Confirm trigger output is enabled.
3. Confirm the processor reaches Ready state.
4. Lower threshold only after validating that the input signal and baseline are stable.
5. Check interval, pulse width, fixed delay, and random delay.
6. Verify that external trigger override is not masking the output.

## External Override Does Not Work

1. Confirm external override is enabled in the control center.
2. Confirm the file path is `d:\cl02_control.bin`.
3. Confirm the file writer uses int32 format.
4. Confirm the workstation has a `D:` drive and write permission.
5. Validate DOUT masking on bench equipment.

## Filter Behavior Is Unexpected

1. Record the selected built-in filter or custom filter file.
2. Confirm moving-average order and formula settings.
3. Recreate the filter with the MATLAB script used to generate it.
4. Confirm firmware image and control-center version.

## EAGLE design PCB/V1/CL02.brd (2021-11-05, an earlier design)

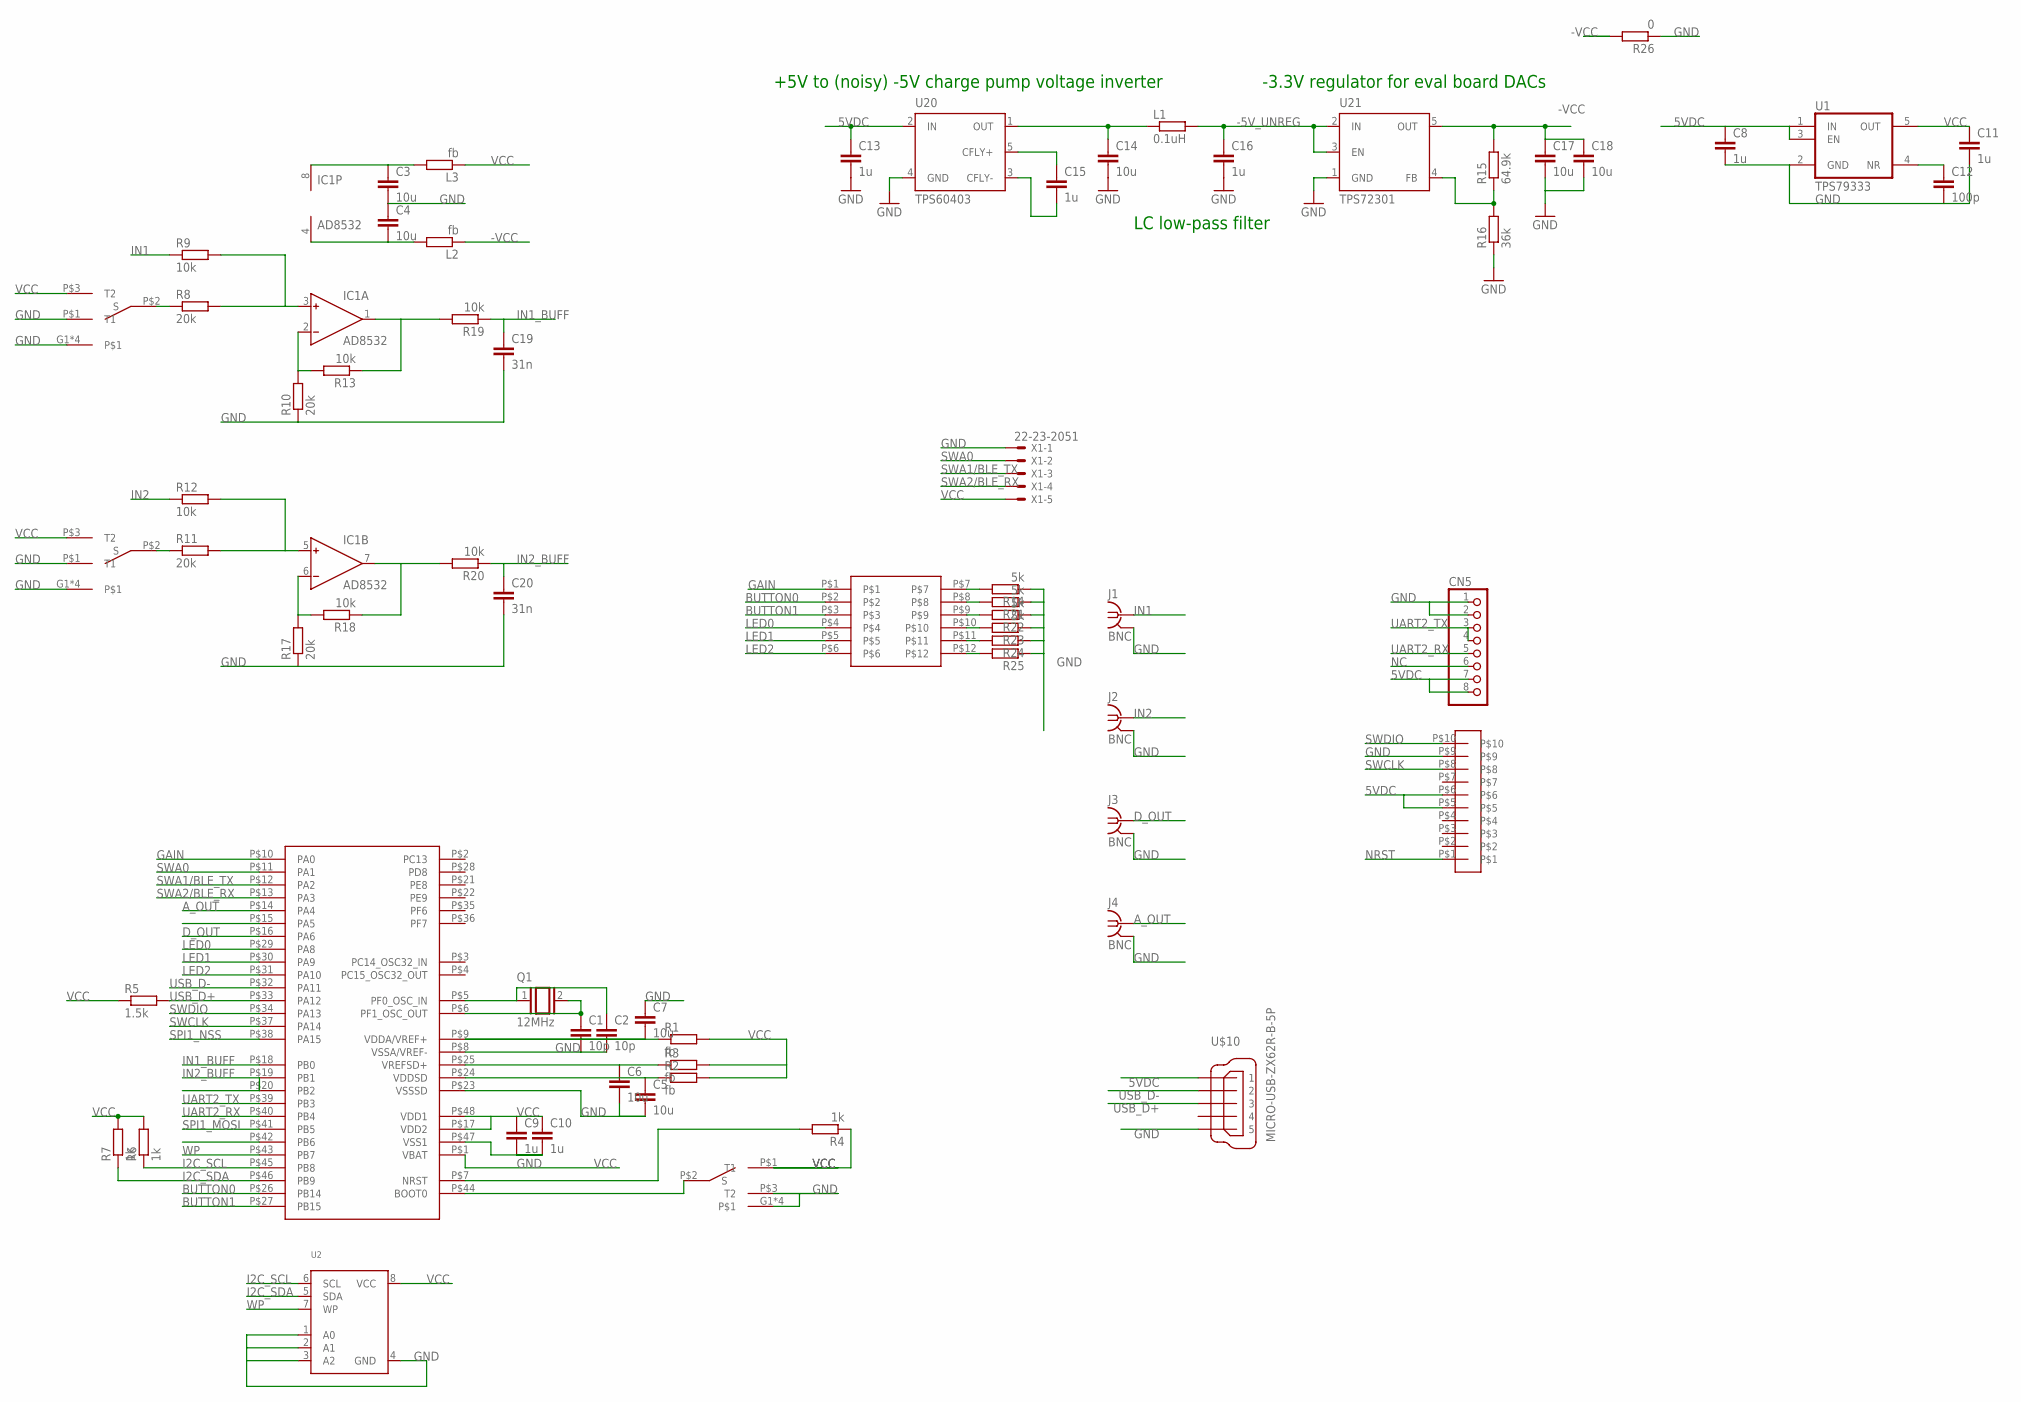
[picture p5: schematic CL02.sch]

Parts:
C1, C2: 10p; C0402
C3, C4, C5, C6, C7, C14, C17, C18: 10u; C0402
C8, C9, C10, C11, C13, C15, C16: 1u; C0402
C12: 100p; C0402
C19, C20: 31n; C0402
CN5: JST_8PIN; JSTPH8
IC1: AD8532; SO8
J1, J2, J3, J4: BNC; BNC-SOCKET
L1: 0.1uH; R0402
L2, L3: fb; R0402
Q1: 12MHz; QS
R1, R2, R3: fb; R0402
R4, R6, R7: 1k; R0402
R5: 1.5k; R0402
R8, R10, R11, R17: 20k; R0402
R9, R12, R13, R18, R19, R20: 10k; R0402
R14, R21, R22, R23: 5k; R0402
R15: 64.9k; R0402
R16: 36k; R0402
R24, R25: RR0402; R0402
R26: 0; R0402
U1: TPS79333; TSOT-23-5
U2: EEPROM_I2C_SOIC8_GENERIC; SOIC8_150MIL
U20: TPS60403; SOT-23-5
U21: TPS72301; SOT-23-5
U$1: STM32F373CCT6; LQFP48
U$6, U$7, U$12: CUS-12B
U$8: 2.54MM_2X6
U$9: 2.54MM_2X5
U$10: MICRO-USB-ZX62R-B-5P; ZX62R-B-5P
X1: 22-23-2051

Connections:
5VDC: C8.1, C13.1, CN5.7, CN5.8, U1.1 (IN), U1.3 (EN), U20.2 (IN), U$9.P$5, U$9.P$6, U$10.1
-5V_UNREG: C16.1, L1.2, U21.2 (IN), U21.3 (EN)
-VCC: C17.1, C18.1, L2.1, R15.2, R26.2, U21.5 (OUT)
A_OUT: J4.A (1), U$1.P$14 (PA4)
BOOT0: U$1.P$44 (BOOT0), U$12.P$2 (S)
BUTTON0: U$1.P$26 (PB14), U$8.P$2
BUTTON1: U$1.P$27 (PB15), U$8.P$3
D_OUT: J3.A (1), U$1.P$16 (PA6)
GAIN: U$1.P$10 (PA0), U$8.P$1
GND: C1.2, C2.2, C3.2, C4.1, C5.2, C6.2, C7.1, C8.2, C9.2, C10.2, C11.2, C12.2, C13.2, C14.2, C16.2, C17.2, C18.2, C19.2, C20.2, CN5.1, CN5.2, J1.SH, J2.SH, J3.SH, J4.SH, R10.1, R14.1, R16.1, R17.1, R21.1, R22.1, R23.1, R24.1, R25.1, R26.1, U1.2 (GND), U2.1 (A0), U2.2 (A1), U2.3 (A2), U2.4 (GND), U20.4 (GND), U21.1 (GND), U$1.P$8 (VSSA/VREF-), U$1.P$23 (VSSSD), U$1.P$47 (VSS1), U$6.G1, U$6.G2, U$6.G3, U$6.G4, U$6.P$1 (T1), U$7.G1, U$7.G2, U$7.G3, U$7.G4, U$7.P$1 (T1), U$9.P$9, U$10.5, U$12.G1, U$12.G2, U$12.G3, U$12.G4, U$12.P$3 (T2), X1.1
I2C_SCL: R6.1, U2.6 (SCL), U$1.P$45 (PB8)
I2C_SDA: R7.1, U2.5 (SDA), U$1.P$46 (PB9)
IN1: J1.A (1), R9.1
IN1_BUFF: C19.1, R19.1, U$1.P$18 (PB0)
IN2: J2.A (1), R12.1
IN2_BUFF: C20.1, R20.1, U$1.P$19 (PB1), U$1.P$20 (PB2)
LED0: U$1.P$29 (PA8), U$8.P$4
LED1: U$1.P$30 (PA9), U$8.P$5
LED2: U$1.P$31 (PA10), U$8.P$6
unnamed: C12.1, U1.4 (NR)
unnamed: IC1.2 (IN-), R10.2, R13.2
unnamed: R25.2, U$8.P$12
unnamed: IC1.1 (OUT), R13.1, R19.2
unnamed: C2.1, Q1.1, U$1.P$5 (PF0_OSC_IN)
unnamed: C1.1, Q1.2, U$1.P$6 (PF1_OSC_OUT)
unnamed: IC1.3 (IN+), R8.2, R9.2
unnamed: C5.1, R2.1, U$1.P$24 (VDDSD)
unnamed: C6.1, R3.1, U$1.P$25 (VREFSD+)
unnamed: C7.2, R1.1, U$1.P$9 (VDDA/VREF+)
unnamed: R8.1, U$6.P$2 (S)
unnamed: IC1.6 (IN-), R17.2, R18.2
unnamed: IC1.7 (OUT), R18.1, R20.2
unnamed: IC1.5 (IN+), R11.2, R12.2
unnamed: R11.1, U$7.P$2 (S)
unnamed: C3.1, IC1.8 (V+), L3.2
unnamed: C4.2, IC1.4 (V-), L2.2
unnamed: R24.2, U$8.P$11
unnamed: R23.2, U$8.P$10
unnamed: R22.2, U$8.P$9
unnamed: R21.2, U$8.P$8
unnamed: R14.2, U$8.P$7
unnamed: C15.1, U20.5 (CFLY+)
unnamed: C15.2, U20.3 (CFLY-)
unnamed: R15.1, R16.2, U21.4 (FB)
unnamed: C14.1, L1.1, U20.1 (OUT)
NC: CN5.6
NRST: R4.2, U$1.P$7 (NRST), U$9.P$1
SPI1_MOSI: U$1.P$41 (PB5)
SPI1_NSS: U$1.P$38 (PA15)
SWA0: U$1.P$11 (PA1), X1.2
SWA1/BLE_TX: U$1.P$12 (PA2), X1.3
SWA2/BLE_RX: U$1.P$13 (PA3), X1.4
SWCLK: U$1.P$37 (PA14), U$9.P$8
SWDIO: U$1.P$34 (PA13), U$9.P$10
UART2_RX: CN5.5, U$1.P$40 (PB4)
UART2_TX: CN5.3, CN5.4, U$1.P$39 (PB3)
USB_D+: R5.2, U$1.P$33 (PA12), U$10.3
USB_D-: U$1.P$32 (PA11), U$10.2
VCC: C9.1, C10.1, C11.1, L3.1, R1.2, R2.2, R3.2, R4.1, R5.1, R6.2, R7.2, U1.5 (OUT), U2.8 (VCC), U$1.P$1 (VBAT), U$1.P$17 (VDD2), U$1.P$48 (VDD1), U$6.P$3 (T2), U$7.P$3 (T2), U$12.P$1 (T1), X1.5
WP: U2.7 (WP), U$1.P$43 (PB7)

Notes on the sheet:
-3.3V regulator for eval board DACs
+5V to (noisy) -5V charge pump voltage inverter
LC low-pass filter

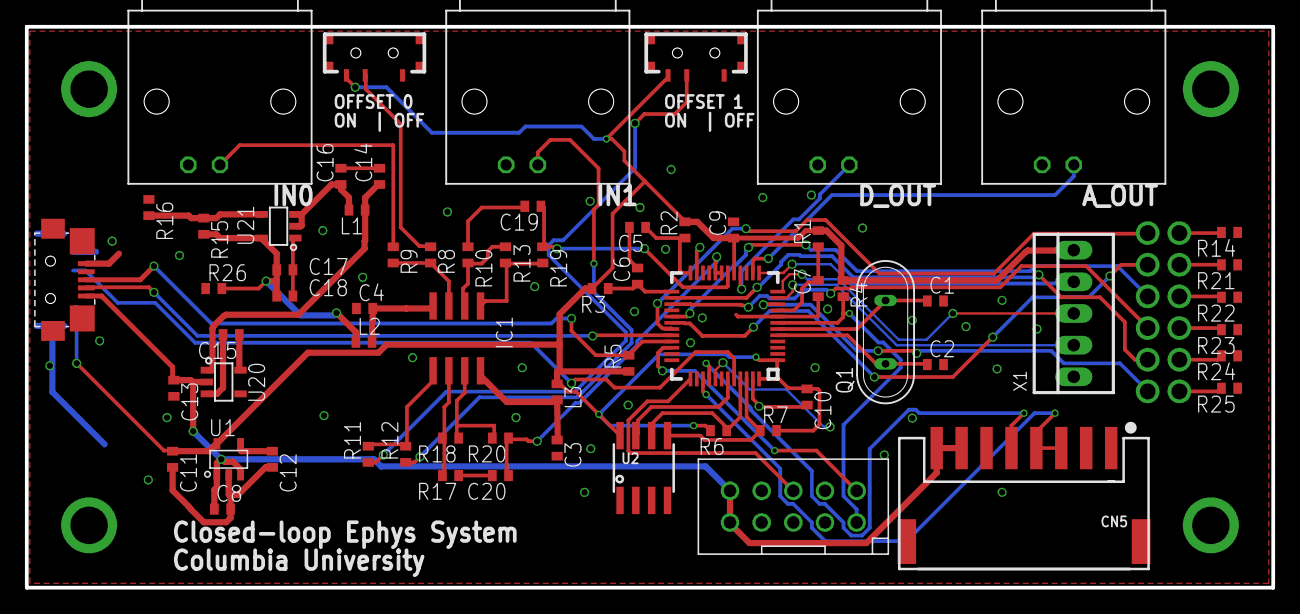
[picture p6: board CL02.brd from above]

Board: 2 copper layers, 100.0 x 45.0 mm, 68 parts (1 on the bottom side), 57 nets.

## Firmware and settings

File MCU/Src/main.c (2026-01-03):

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
/* Includes ------------------------------------------------------------------*/
#include "main.h"
#include "usb_device.h"

/* USER CODE BEGIN Includes */
#include "dataMGR.h"
#include "usbd_cdc.h"
#include "usbd_cdc_if.h"
#include "HD32_filter.h"
#include "CE32_USB_INTERCOM.h"
#include "CE32_Stimulator.h"
#include "CE32_ClosedLoop.h"
#define kFS 1000
#define FM_version 31
/* USER CODE END Includes */

ADC_HandleTypeDef hadc1;

DAC_HandleTypeDef hdac1;

I2C_HandleTypeDef hi2c1;

SDADC_HandleTypeDef hsdadc1;
SDADC_HandleTypeDef hsdadc2;
SDADC_HandleTypeDef hsdadc3;
DMA_HandleTypeDef hdma_sdadc1;
DMA_HandleTypeDef hdma_sdadc2;
DMA_HandleTypeDef hdma_sdadc3;

TIM_HandleTypeDef htim2;
TIM_HandleTypeDef htim5;
TIM_HandleTypeDef htim16;
TIM_HandleTypeDef htim17;
TIM_HandleTypeDef htim18;

UART_HandleTypeDef huart2;

/* USER CODE BEGIN PV */
int16_t adc_buf[2];
int16_t data_buf[BUF_SIZE/2];
dataMGR MGR;
CE32_systemParam 	sysParam;

CE32_dspParam    sysDSP[2];
CE32_Filter			 mainFil[2];
CE32_Filter   	 maFil[2];
CE32_StimControl sc[2];
CE32_CL					 cl;
const int trans_size=256;
uint16_t misc_DigiSig;
uint16_t test;
float dsp_gain=10;
extern HD32_filter_coeff filter_custom_coeff[2];

uint8_t TX_buf[8]; //TX buffer, with extra bytes as reserve
uint8_t TX_buf_state=0;

void (*arbitarCal_CH1)(uchar* ch_ord,short* data,float* output);
void (*arbitarCal_CH2)(uchar* ch_ord,short* data,float* output);

CE32_USB_INTERCOM_Handle IC_USB_handle;

CE32_stimulator STIM_handle[2];
/* USER CODE END PV */

void SystemClock_Config(void);
static void MX_GPIO_Init(void);
static void MX_DMA_Init(void);
static void MX_DAC1_Init(void);
static void MX_SDADC1_Init(void);
static void MX_SDADC2_Init(void);
static void MX_I2C1_Init(void);
static void MX_ADC1_Init(void);
static void MX_TIM2_Init(void);
static void MX_TIM18_Init(void);
static void MX_TIM16_Init(void);
static void MX_TIM17_Init(void);
static void MX_USART2_UART_Init(void);
static void MX_SDADC3_Init(void);
static void MX_TIM5_Init(void);
/* USER CODE BEGIN PFP */
int CL02_CmdSvr(uint8_t *data_ptr,uint32_t cmd_len);
int CL02_sendDataPackage();
int CL02_purgeData();
int CL02_setClParam();
/* USER CODE END PFP */

/**
  * @brief  The application entry point.
  * @retval int
  */
int main(void)
{
  /* MCU Configuration--------------------------------------------------------*/

  /* Reset of all peripherals, Initializes the Flash interface and the Systick. */
  HAL_Init();

  /* USER CODE BEGIN Init */
	//Validate_ChipId();
  /* USER CODE END Init */

  /* Configure the system clock */
  SystemClock_Config();

  /* Initialize all configured peripherals */
  MX_GPIO_Init();
  MX_DMA_Init();
  MX_DAC1_Init();
  MX_SDADC1_Init();
  MX_SDADC2_Init();
  MX_USB_DEVICE_Init();
  MX_I2C1_Init();
  MX_ADC1_Init();
  MX_TIM2_Init();
  MX_TIM18_Init();
  MX_TIM16_Init();
  MX_TIM17_Init();
  MX_USART2_UART_Init();
  MX_SDADC3_Init();
  MX_TIM5_Init();
  /* USER CODE BEGIN 2 */
	//HAL_TIM_Base_Start(&htim2);
	//HAL_TIM_PWM_Start(&htim2,TIM_CHANNEL_4);
	HAL_TIM_PWM_Start(&htim5,TIM_CHANNEL_1);
	
	dataMGR_init(&MGR,(char*) data_buf,sizeof(data_buf));					//FIFO setup 
	sysParam.fs = kFS;
	sysParam.firm_version = FM_version;
	CE32_CL_Init(&cl,&sysParam,sysDSP,mainFil,maFil,sc); //Initialize Closed-loop unit
	CE32_CL_Start(&cl);
	
	HAL_SDADC_CalibrationStart(&hsdadc1,SDADC_CALIBRATION_SEQ_3);
	HAL_SDADC_CalibrationStart(&hsdadc2,SDADC_CALIBRATION_SEQ_3);
	HAL_SDADC_ConfigChannel(&hsdadc1,SDADC_CHANNEL_6,SDADC_CONTINUOUS_CONV_ON);
	HAL_SDADC_ConfigChannel(&hsdadc2,SDADC_CHANNEL_6,SDADC_CONTINUOUS_CONV_ON);
	//HAL_SDADC_Start_DMA(&hsdadc1,(uint32_t*)adc_buf,1);
	
	hsdadc1.Instance->CR1 |= SDADC_CR1_RDMAEN;
	HAL_DMA_Start_IT(hsdadc1.hdma, (uint32_t)&hsdadc1.Instance->RDATAR, (uint32_t) adc_buf, 1);
	hsdadc1.Instance->CR2 |= SDADC_CR2_RSWSTART;
	hsdadc2.Instance->CR1 |= SDADC_CR1_RDMAEN;
	HAL_DMA_Start_IT(hsdadc2.hdma, (uint32_t)&hsdadc2.Instance->RDATAR, (uint32_t) (adc_buf+1), 1);
	hsdadc2.Instance->CR2 |= SDADC_CR2_RSWSTART;
	
	//Stimulator initializing
	CE32_STIM_Init(&STIM_handle[0],&htim16,0,0);
	CE32_STIM_Init(&STIM_handle[1],&htim17,0,1);
	CE32_STIM_Setup(&STIM_handle[0],sysParam.stim_intensity[0],sysParam.stim_delay[0]+rand()*sysParam.stim_RndDelay[0],sysParam.stim_interval[0],sysParam.pulse_cnt[0],sysParam.pulse_width[0]);
	CE32_STIM_Setup(&STIM_handle[1],sysParam.stim_intensity[0],sysParam.stim_delay[0]+rand()*sysParam.stim_RndDelay[0],sysParam.stim_interval[0],sysParam.pulse_cnt[0],sysParam.pulse_width[0]);
	//CE32_STIM_Setup(&STIM_handle[1],sysParam.stim_intensity[1],sysParam.stim_delay[1]+rand()*sysParam.stim_RndDelay[1],sysParam.stim_interval[1],sysParam.pulse_cnt[1],sysParam.pulse_width[1]);

	HAL_DAC_Start(&hdac1,DAC_CHANNEL_1);
	//start ticking timer
	HAL_TIM_Base_Start_IT(&htim18);
  /* USER CODE END 2 */

  /* Infinite loop */
  /* USER CODE BEGIN WHILE */
  while (1)
  {
    /* USER CODE END WHILE */

    /* USER CODE BEGIN 3 */
		
		if(MGR.bufferUsed[0]>trans_size){
			if(MGR.sysState&MGR_SYS_PREVIEW){
				CL02_sendDataPackage();
			}
			else{
				CL02_purgeData();
			}
		}
		
		if(MGR.bufferUsed[0]>BUF_SIZE){
			CL02_purgeData();
		}
		
		uint8_t *data_ptr;
		uint32_t cmd_len;
		
		if(CE32_USB_INTERCOM_RX_DequeueCmd(&IC_USB_handle,&data_ptr,&cmd_len)==0)
		{
			CL02_CmdSvr(data_ptr,cmd_len);
		}
  }
  /* USER CODE END 3 */
}

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
/* USER CODE BEGIN 4 */

int CL02_CmdSvr(uint8_t *data_ptr,uint32_t cmd_len)
{
	/*CMD ID: 
		
		0x01.	update SYS 
		0x02.	update DSP1

		0x10. Threshold setting(std.)
		0x11. state control (stimulation/closed loop)
		0x14. Threshold setting(abs.)
	
		0x20. stimulation timing control
		0x21. DSP setting
	
		
		0x40. Start Preview
		0x41. Stop Preview

		*/
	switch(data_ptr[0])
	{
		case 0x01:
			memcpy(((uint8_t*)&sysParam),&data_ptr[1],CE32_SYSPARAM_WR_LEN);

			CE32_CL_Init(&cl,&sysParam,sysDSP,mainFil,maFil,sc); //Initialize Closed-loop unit
			CE32_STIM_Setup(&STIM_handle[0],sysParam.stim_intensity[0],sysParam.stim_delay[0]+rand()*sysParam.stim_RndDelay[0],sysParam.stim_interval[0],sysParam.pulse_cnt[0],sysParam.pulse_width[0]);
			
			//DF_StimControl_Setting(&sc[0],sysParam.fs,sysParam.trigger_trainStart,sysParam.trigger_trainDuration,sysParam.pulse_width[0],sysParam.stim_interval[0],sysParam.stim_delay[0],sysParam.stim_RndDelay[0],sysParam.trigger_gain[0]);
			//DF_StimControl_Setting(&sc[1],sysParam.fs,sysParam.trigger_trainStart,sysParam.trigger_trainDuration,sysParam.pulse_width[1],sysParam.stim_interval[1],sysParam.stim_delay[1],sysParam.stim_RndDelay[1],sysParam.trigger_gain[1]);
			CE32_CL_Start(&cl);
			CL02_setClParam();
			break;
		case 0x02:
			memcpy(&sysDSP[0],&data_ptr[1],512);
			//CE32_arbitar_Init(&arbitarCal_CH1,&sysDSP[0]);			//Init pointer for signal arbitar
			CE32_CL_Init(&cl,&sysParam,sysDSP,mainFil,maFil,sc); //Initialize Closed-loop unit
			CE32_CL_Start(&cl);
			break;
		case 0x06: //Load custom filter
		{
			uint8_t id = *(uint8_t*)&data_ptr[1]; //index of custom filter
			uint8_t type=*(uint8_t*)&data_ptr[2]; //first data is uint8,type(01=DF1,02=SOS)
			uint16_t ord=*(uint16_t*)&data_ptr[3]; //2nd data is uint16
			filter_custom_coeff[id].ord=ord;
			int* ptr=(int*)&data_ptr[5];
			memcpy(&filter_custom_coeff[id].NL,ptr,ord*sizeof(int));
			float* fptr=(float*)&data_ptr[5+ord*sizeof(int)];
			memcpy(&filter_custom_coeff[id].Num,&fptr[0],3*ord*sizeof(float));
			memcpy(&filter_custom_coeff[id].Den,&fptr[3*ord],3*ord*sizeof(float));
//			sysDSP[id].func1=CE32_FILTER_CUSTOM;
//			CE32_CL_Init(&cl,&sysParam,sysDSP,mainFil,maFil,sc); //Initialize Closed-loop unit
//			CE32_CL_Start(&cl);
			break;
		}
		case 0x10://Gain setting realtime
		{
			float v;
			uint8_t *ptr;
			uint8_t id = data_ptr[1];
			ptr=(uint8_t*)&v;
			for(int i=0;i<4;i++){
				*(ptr+i)=data_ptr[i+2];
			}
			sc[id].Trig_gain=v;
			sc[id].Trig_level=sc[id].Trig_gain*sc[id].Trig_mean;
			break;
		}
		case 0x11://STIM on/off
		{
			if(data_ptr[1]==0){
				//sc->Trig_state=~SC_STATE_ON;
				sysParam.stim_mode=0;
				CE32_STIM_DISABLE(&STIM_handle[0]);
			}
			else{
				//sc->Trig_state|=SC_STATE_ON;
				sysParam.stim_mode=1;
				CE32_STIM_ENABLE(&STIM_handle[0]);
			}
				break;
		}
		case 0x12: //Trig mode
		{
			if(data_ptr[1]==0){
				cl.trig_mode = 0;
				STIM_handle[0].trig_mode = 0;
				STIM_handle[1].trig_mode = 0;
			}
			else
			{
				cl.trig_mode = 1;
				STIM_handle[0].trig_mode = 1;
				STIM_handle[1].trig_mode = 1;
			}
			break;
		}
		case 0x14:
		{
			float v;
			uint8_t *ptr;
			uint8_t id = data_ptr[1];
			ptr=(uint8_t*)&v;
			for(int i=0;i<4;i++){
				*(ptr+i)=data_ptr[i+2];
			}
			sc[id].Trig_level=v;
			break;
		}
		case 0x15: //set cl params
		{		
			memcpy(sysParam.cl_param1,&data_ptr[1],sizeof(sysParam.cl_param1));
			memcpy(sysParam.cl_param2,&data_ptr[1]+sizeof(sysParam.cl_param1),sizeof(sysParam.cl_param2));
			break;
		}
		case 0x20:
		{
			uint32_t* ptr=(uint32_t*)(&data_ptr[2]);
			uint8_t id=data_ptr[1];
			STIM_handle[id].delay=ptr[0];
			STIM_handle[id].random_delay=ptr[1];
			STIM_handle[id].duration=ptr[2];
			STIM_handle[id].interval=ptr[3];
			STIM_handle[id].cycle=ptr[4];
			break;
		}
		case 0x21:
		{
			uint32_t * ptr=(uint32_t*)(&data_ptr[2]);
			uint8_t id=data_ptr[1];
			sysDSP[id].MAOrd=ptr[0];
			sysDSP[id].func1=ptr[1];
			sysDSP[id].formula=ptr[2];
			CE32_InitFilter(&mainFil[id],&maFil[id],&sysDSP[id]);
			cl.rectifier[id] = (sysDSP[id].func1==CE32_FILTER_DELTA)?0:1;
			break;
		}
		case 0x40:
		{
			MGR.sysState|=MGR_SYS_PREVIEW;
			break;
		}
		case 0x41:
		{
			MGR.sysState=~MGR_SYS_PREVIEW;
			break;
		}
		case 0x60:
		{
			uint32_t* ptr=(uint32_t*)(&data_ptr[1]);
			dsp_gain=ptr[0]/10;
			break;
		}
		case 0x83:
		{
			CE32_STIM_Trig(&STIM_handle[0]);
			break;
		}
	}
	return 0;
}

void CE32_CL_TrigAct(int id) //Triggers when Closed-loop detect a event
{
	CE32_STIM_Trig(&STIM_handle[id]);
}

void CE32_CL_TrigStopAct(int id) //Triggers when Closed-loop detect a event
{
	CE32_STIM_Abort(&STIM_handle[id]);
}

void CE32_CL_WaitAct(int id)
{
	if(id==0)
	{
		htim5.Instance->ARR=9999;
		htim5.Instance->CCR4=4999;
		HAL_TIM_PWM_Start(&htim5,TIM_CHANNEL_1);
		misc_DigiSig|=MISC_SIG_DSP_WAIT;
		misc_DigiSig&=~(MISC_SIG_DSP_CAL|MISC_SIG_DSP_READY);
	}
}

void CE32_CL_TrainAct(int id) //Triggers when traning starting
{
	if(id==0)
	{
		htim5.Instance->ARR=4999;
		htim5.Instance->CCR4=2499;
		misc_DigiSig|=MISC_SIG_DSP_CAL;
		misc_DigiSig&=~(MISC_SIG_DSP_WAIT|MISC_SIG_DSP_READY);
	}
}

void CE32_CL_ReadyAct(int id) //Triggers when traning is done
{
	if(id==0)
	{
		htim5.Instance->ARR=4999;
		htim5.Instance->CCR4=4999;
		misc_DigiSig|=MISC_SIG_DSP_READY;
		misc_DigiSig&=~(MISC_SIG_DSP_CAL|MISC_SIG_DSP_WAIT);
	}
}

void CE32_CL_TrigInitAct(int id)
{
	MX_TIM16_Init();
	MX_TIM17_Init();
	CE32_STIM_StimOffAct(&STIM_handle[0]);
	CE32_STIM_StimOffAct(&STIM_handle[1]);
	CE32_STIM_Init(&STIM_handle[0],&htim16,0,0);
	CE32_STIM_Init(&STIM_handle[1],&htim17,0,1);
	CE32_STIM_Setup(&STIM_handle[0],sysParam.stim_intensity[0],sysParam.stim_delay[0]+rand()*sysParam.stim_RndDelay[0],sysParam.stim_interval[0],sysParam.pulse_cnt[0],sysParam.pulse_width[0]);
	CE32_STIM_Setup(&STIM_handle[1],sysParam.stim_intensity[1],sysParam.stim_delay[1]+rand()*sysParam.stim_RndDelay[1],sysParam.stim_interval[1],sysParam.pulse_cnt[1],sysParam.pulse_width[1]);

}

void CE32_STIM_TrigAct(CE32_stimulator* handle)//Trigger Onset action, Define this action in IT
{
	PIN_SET(LED1);
	PIN_SET(DOUT1);
	switch(handle->id){
		case 0:
			misc_DigiSig|=MISC_SIG_TRIG1;
			break;
		case 1:
			misc_DigiSig|=MISC_SIG_TRIG2;
			break;
	}
}
void CE32_STIM_StimAct(CE32_stimulator* handle)//Stimulation Onset action, Define this action in IT
{
	if(sysParam.stim_mode ==1)
	{
		PIN_SET(LED0);
		switch(handle->id){
			case 0:
				misc_DigiSig|=MISC_SIG_STIM1;
				PIN_SET(DOUT);
				break;
			case 1:
				misc_DigiSig|=MISC_SIG_STIM2;
				PIN_SET(DOUT);
				break;
		}
	}
}

void CE32_STIM_TrigStopAct(CE32_stimulator* handle)
{
	PIN_RESET(LED1);
	PIN_RESET(DOUT1);
	switch(handle->id){
		case 0:
			misc_DigiSig&=~(MISC_SIG_TRIG1);
			break;
		case 1:
			misc_DigiSig&=~(MISC_SIG_TRIG2);
			break;
	}
}

void CE32_STIM_StimOffAct(CE32_stimulator* handle)
{
	PIN_RESET(LED0);
	switch(handle->id){
		case 0:
			PIN_RESET(DOUT);
			misc_DigiSig&=~MISC_SIG_STIM1;
			break;
		case 1:
			PIN_RESET(DOUT);
			misc_DigiSig&=~MISC_SIG_STIM2;
			break;
	}
}

void CE32_STIM_StimStopAct(CE32_stimulator* handle)
{
	PIN_RESET(LED0);
	switch(handle->id){
		case 0:
			PIN_RESET(DOUT);
			misc_DigiSig&=~MISC_SIG_STIM1;
			break;
		case 1:
			PIN_RESET(DOUT);
			misc_DigiSig&=~MISC_SIG_STIM2;
			break;
	}
}

void CE32_STIM_StimAbortAct(CE32_stimulator* handle)
{
	PIN_RESET(LED0);
	PIN_RESET(LED1);
	misc_DigiSig&=~(MISC_SIG_TRIG1|MISC_SIG_STIM1|MISC_SIG_TRIG2|MISC_SIG_STIM2);
}


int CL02_sendDataPackage(){
	switch(TX_buf_state){
		case 0:	{ //Send header
			TX_buf[0]=0x3c;
			TX_buf[1]=0xAD;
		
			float temp=cl.sc[0]->Trig_level;
			temp=temp>INT16_MAX?INT16_MAX:temp;			//Make sure temp is not saturated 
			temp=temp<INT16_MIN?INT16_MIN:temp;			//Make sure temp is not saturated 
			*((int16_t*)&TX_buf[2])=temp;
			temp=cl.sc[1]->Trig_level;
			temp=temp>INT16_MAX?INT16_MAX:temp;			//Make sure temp is not saturated 
			temp=temp<INT16_MIN?INT16_MIN:temp;			//Make sure temp is not saturated 
			*((int16_t*)&TX_buf[4])=temp;
			if(CDC_Transmit_FS(TX_buf,6)==USBD_OK){
				TX_buf_state=1;
			}
			break;
		}
		case 1:{ //Send package
			if(CDC_Transmit_FS(((uint8_t*)data_buf)+MGR.outPTR[0],trans_size)==USBD_OK){
				TX_buf_state=2;
				dataMGR_deQueue(&MGR,trans_size,0);
			}
			break;
		}
		case 2:{//Send tail
			uint8_t TX_tail = 0x3e;
			if(CDC_Transmit_FS(&TX_tail,1)==USBD_OK){
				TX_buf_state=0;
			}
			break;
		}
	}
}

int CL02_purgeData(){
	dataMGR_deQueue(&MGR,trans_size,0);	
	TX_buf_state=0;
}

int CL02_setClParam()
{
	if(sysParam.stim_mode==0){
		CE32_STIM_DISABLE(&STIM_handle[0]);
		CE32_STIM_DISABLE(&STIM_handle[1]);
	}
	else{
		CE32_STIM_ENABLE(&STIM_handle[0]);
		CE32_STIM_ENABLE(&STIM_handle[1]);
	}
}

/* USER CODE END 4 */
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


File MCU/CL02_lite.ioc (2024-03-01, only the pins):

Mcu.UserName=STM32F373CCTx
PA0.GPIO_Label=GAIN
PA0.Signal=ADC1_IN0
PA10.GPIO_Label=LED0
PA10.Signal=GPIO_Output
PA11.Signal=USB_DM
PA12.Signal=USB_DP
PA13.Signal=SYS_JTMS-SWDIO
PA14.Signal=SYS_JTCK-SWCLK
PA2.Signal=S_TIM2_CH3
PA4.GPIO_Label=AOUT
PA4.Signal=COMP_DAC11_group
PA5.GPIO_Label=DOUT1
PA5.Signal=GPIO_Output
PA6.GPIO_Label=DOUT
PA6.Signal=GPIO_Output
PA8.GPIO_Label=LED2
PA8.Signal=S_TIM5_CH1_ETR
PA9.GPIO_Label=LED1
PA9.Signal=GPIO_Output
PB0.GPIO_Label=IN0
PB0.Signal=SDADC1_AIN6P
PB1.GPIO_Label=IN2_back
PB1.Signal=GPIO_Analog
PB14.Signal=GPIO_Input
PB15.GPIO_Label=BUTTON0
PB15.Signal=GPIO_Input
PB2.GPIO_Label=IN1
PB2.Signal=SharedAnalog_PB2
PB3.Signal=USART2_TX
PB4.Signal=USART2_RX
PB5.Signal=SPI1_MOSI
PB8.Signal=I2C1_SCL
PB9.Signal=I2C1_SDA
PD8.GPIO_Label=IN3
PD8.Signal=SDADC3_AIN6P
PF0-OSC_IN.Signal=RCC_OSC_IN
PF1-OSC_OUT.Signal=RCC_OSC_OUT

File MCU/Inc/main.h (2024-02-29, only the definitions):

#define GAIN_Pin GPIO_PIN_0
#define GAIN_GPIO_Port GPIOA
#define AOUT_Pin GPIO_PIN_4
#define AOUT_GPIO_Port GPIOA
#define DOUT1_Pin GPIO_PIN_5
#define DOUT1_GPIO_Port GPIOA
#define DOUT_Pin GPIO_PIN_6
#define DOUT_GPIO_Port GPIOA
#define IN0_Pin GPIO_PIN_0
#define IN0_GPIO_Port GPIOB
#define IN2_back_Pin GPIO_PIN_1
#define IN2_back_GPIO_Port GPIOB
#define IN1_Pin GPIO_PIN_2
#define IN1_GPIO_Port GPIOB
#define BUTTON0_Pin GPIO_PIN_15
#define BUTTON0_GPIO_Port GPIOB
#define IN3_Pin GPIO_PIN_8
#define IN3_GPIO_Port GPIOD
#define LED2_Pin GPIO_PIN_8
#define LED2_GPIO_Port GPIOA
#define LED1_Pin GPIO_PIN_9
#define LED1_GPIO_Port GPIOA
#define LED0_Pin GPIO_PIN_10
#define LED0_GPIO_Port GPIOA

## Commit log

2021-11-05 Initial commit, V1.04
    [CL02.brd, CL02.sch, CL02_default_BOM_values.xlsx]
2022-01-04 % major update V1.0.1.0 Improved wave display, solved sub-sampling problem Change random trigger timer base to 100ms. Added a firmVersion to systemParam Added a copy byte limitation guard to cmd_svr 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
    [main.c]
2024-01-04 Fixed gated mode with two threshold controls. Known bug: If triggered too fast, the stimulator will stuck and will not come back unless a hard reset
    [main.c]
2024-01-10 V1.0.6 added 100-200,8-40Hz filter
2024-01-11 V1.0.7: fixed DSP id setting mixing problem Added 2nd custom filter support
    [main.c]
2024-02-05 Rectifier Lowpass filter changed to butterworth
2024-02-05 Ported Pin def to V2.0 board
2024-02-29 % version 2_0_2_0 Trigger signal output at AOUT2 Stim off will not turn filter off Filter updated with order1 IIR Filter generation file in Matlab
2024-03-01 Fixed delay function in C# Added trigger on-hold function (Trigger on First/Last event)
    [CE32_stimulator.c, CL02_lite.ioc]
2024-03-08 Uploaded V2 PCB
    [CL02.brd, CL02.sch, CL02_V2.brd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]
2024-04-02 Updated filter
2024-08-19 Improved Delta filter
2024-10-24 HTF filter generation
2025-01-16 Filter update: THeta changed to 4-12 Hz
2025-01-17 in progress to improve phase decoding, with different filters
2025-01-17 Filter update Reordered filterdef.h
2025-01-17 updated filters with individual variable names. added command 15 support in device for uploading CL paramters
2025-12-05 Updated PCB production files with latest partlist
    [CL02_V2.csv, CL02_V2_BOM.xlsx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]
2025-12-05 Removed outdated bom files
    [CL02_V2_BOM.csv, CL02_V2_default_BOM_values.csv]
2026-01-03 Uploaded filter simulation/generation files in matlab
2026-01-03 Updated dataMGR to avoid racing conditions induced processing delay
    [main.c]
2026-03-31 Updated BNC connector info
    [CL02_V2_BOM.xlsx]

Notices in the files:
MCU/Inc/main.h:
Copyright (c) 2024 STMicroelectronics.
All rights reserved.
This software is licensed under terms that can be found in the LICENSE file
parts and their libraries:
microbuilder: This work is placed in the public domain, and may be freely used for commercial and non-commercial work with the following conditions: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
